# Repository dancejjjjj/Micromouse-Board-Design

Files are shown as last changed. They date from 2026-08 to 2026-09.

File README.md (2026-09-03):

# Micromouse Hardware Design (KiCad)

Hardware schematics and design files for an autonomous Micromouse robot based on the **ESP32-S3 SuperMini**.

---

> ⚠️ **IMPORTANT NOTICE:**  
> The physical hardware of this robot is built entirely on a **Prototype Board (Perfboard/Dot board)** using manual point-to-point soldering.  
> The included **PCB layout file (`.kicad_pcb`) is provided for reference only** (visualizing routing logic and footprint planning) and **has NOT been tested or validated for direct PCB manufacturing**. Please refer to the **Schematic (`.kicad_sch`)** for wiring connections when assembling on a proto-board or designing your custom PCB.

---

## 🧩 Bill of Materials (Key Components)

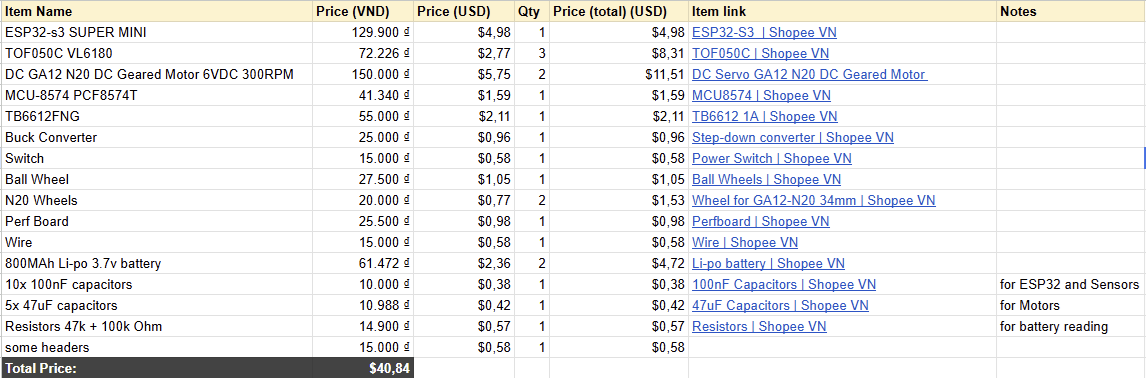
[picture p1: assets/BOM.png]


Google sheet link here:
https://docs.google.com/spreadsheets/d/1piouLKvGbAHOj3b3Lox_jSpBq9OYytLLw8UId9fDQRM/edit?usp=sharing

---

## 📁 Repository Structure

```text
.
├── pcb/
│   ├── micromouse.kicad_pro     # KiCad Project File
│   ├── micromouse.kicad_sch     # Full Circuit Schematic (Primary reference)
│   └── micromouse.kicad_pcb     # Reference PCB Layout (Do NOT fabricate directly)
|   
├── BOM.csv
└── README.md
```
## View it 
https://kicanvas.org/?repo=https%3A%2F%2Fgithub.com%2Fdancejjjjj%2FMicromouse-Board-Design%2Ftree%2Fmain%2Fpcb

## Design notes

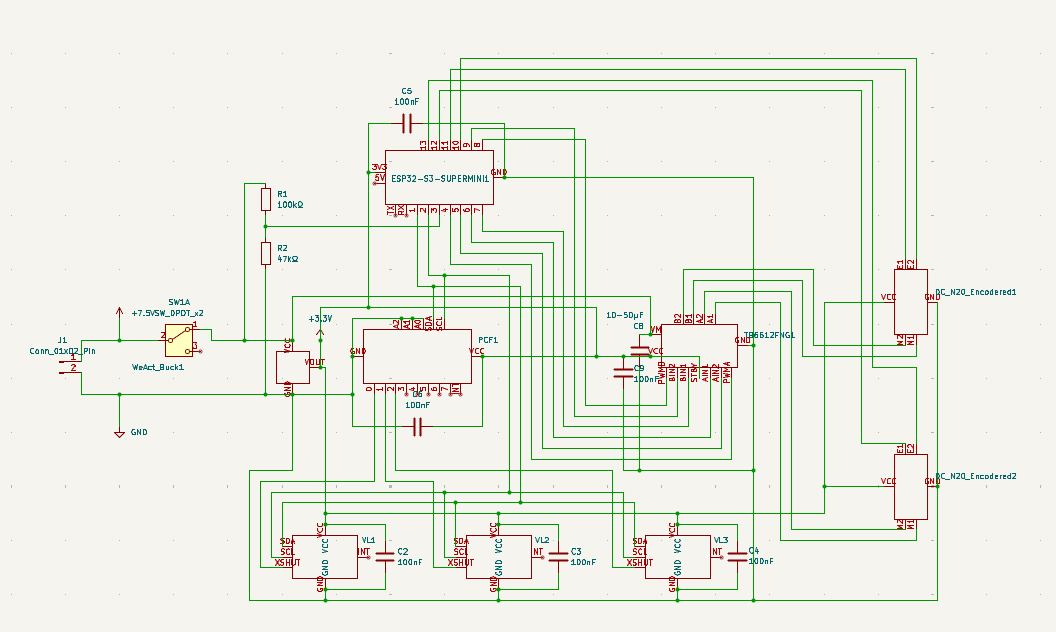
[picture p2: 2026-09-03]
assets/Schematic.png

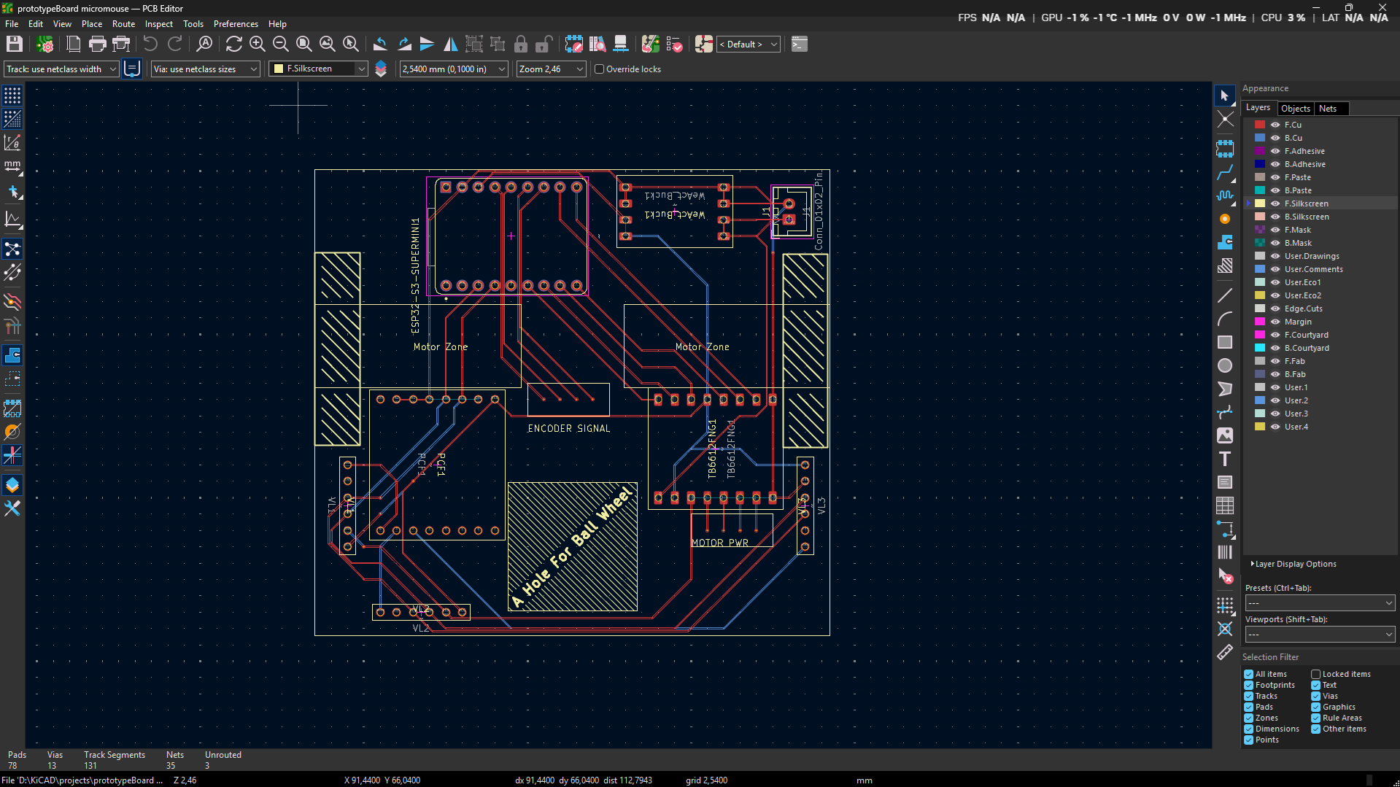
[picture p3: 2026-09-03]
assets/PCB.png

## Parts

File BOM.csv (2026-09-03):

Item Name | Price (VND) | Price (USD) | Qty | Price (total) (USD) | Item link | Notes
ESP32-s3 SUPER MINI | 129.900 ₫ | $4,98 | 1 | $4,98 | https://shopee.vn/ESP32-S3-SuperMini-WiFi-Bluetooth-BLE-5.0-Type-C-Dev-Board-240MHz-4MB-Flash-Ch%C3%ADnh-H%C3%A3ng-i.298106917.46503331606
TOF050C VL6180 | 72.226 ₫ | $2,77 | 3 | $8,31 | https://shopee.vn/M%C3%B4-%C4%91un-c%E1%BA%A3m-bi%E1%BA%BFn-ph%E1%BA%A1m-vi-TOF050C-TOF200C-TOF400C-Kho%E1%BA%A3ng-c%C3%A1ch-chuy%E1%BA%BFn-bay-ToF-%C4%91%E1%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
DC GA12 N20 DC Geared Motor 6VDC 300RPM | 150.000 ₫ | $5,75 | 2 | $11,51 | https://hshop.vn/dong-co-dc-giamtoc-ga12-n20-encoder
MCU-8574 PCF8574T | 41.340 ₫ | $1,59 | 1 | $1,59 | https://shopee.vn/Ah-ROBOT-%E3%80%91-PCF8574-PCF8574T-I-O-cho-giao-di%E1%BB%87n-c%E1%BB%95ng-I2C-IIC-H%E1%BB%97-tr%E1%BB%A3-m%C3%B4-%C4%91un-m%E1%BB%9F-r%E1%B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
TB6612FNG | 55.000 ₫ | $2,11 | 1 | $2,11 | https://shopee.vn/Tr%C3%ACnh-%C4%90i%E1%BB%81u-Khi%E1%BB%83n-%C4%90%E1%BB%99ng-C%C6%A1-K%C3%A9p-TB6612-1A-TB6612FNG-Cho-Arduino-L298N-i.578443443.23647942735
Buck Converter | 25.000 ₫ | $0,96 | 1 | $0,96 | https://shopee.vn/WeAct-M%E1%BA%A1ch-Buck-Step-Down-H%E1%BA%A1-%C3%A1p-DC-DC-0.6A-ch%C3%ADnh-h%C3%A3ng-i.882588972.28041630831
Switch | 15.000 ₫ | $0,58 | 1 | $0,58 | https://shopee.vn/5-C%C3%A1i-C%C3%B4ng-t%E1%BA%AFc-g%E1%BA%A1t-3-ch%E1%BA%A5u-on-off-(lo%E1%BA%A1i-t%E1%BB%91t).-C%C3%B4ng-t%E1%BA%AFc-MTS102-6A-125V-3A-250V.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
Ball Wheel | 27.500 ₫ | $1,05 | 1 | $1,05 | https://shopee.vn/B%C3%A1nh-xe-%C4%91a-h%C6%B0%E1%BB%9Bng-con-l%C4%83n-bi-c%E1%BA%A7u-v%C3%B2ng-bi-c%E1%BA%A7u-CY15A-CY25A-lo%E1%BA%A1i-chu%E1%BA%A9n-i.599614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
N20 Wheels | 20.000 ₫ | $0,77 | 2 | $1,53 | https://shopee.vn/B%C3%A1nh-xe-%C4%91%E1%BB%99ng-c%C6%A1-GA12-N20-34mm-i.494330825.8781429510
Perf Board | 25.500 ₫ | $0,98 | 1 | $0,98 | https://shopee.vn/Bo-M%E1%BA%A1ch-%C4%90%E1%BB%A5c-L%E1%BB%97-S%E1%BA%B5n-Nhi%E1%BB%81u-K%C3%ADch-Th%C6%B0%E1%BB%9Bc-Kho%E1%BA%A3ng-C%C3%A1ch-L%E1%BB%97-2.54m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
Wire | 15.000 ₫ | $0,58 | 1 | $0,58 | https://shopee.vn/-Linh-Ki%E1%BB%87n-%C4%90i%E1%BB%87n-T%E1%BB%AD-2M-D%C3%A2y-%C4%90%E1%BB%93ng-1-L%C3%B5i-0.6mm-C%E1%BA%AFm-Tesboard-N%E1%BB%91i-M%E1%BA%A1ch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
800MAh Li-po 3.7v battery | 61.472 ₫ | $2,36 | 2 | $4,72 | https://shopee.vn/Pin-s%E1%BA%A1c-Lipo-3.7V-Dung-L%C6%B0%E1%BB%A3ng-T%E1%BB%AB-50-10000mAh-c%C3%B3-m%E1%BA%A1ch-b%E1%BA%A3o-v%E1%BB%87-pin-cho-tai-nghe-%C4%91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
10x 100nF capacitors | 10.000 ₫ | $0,38 | 1 | $0,38 | https://shopee.vn/-T%C3%BAi-10-con-T%E1%BB%A5-%C4%91i%E1%BB%87n-g%E1%BB%91m-kh%C3%B4ng-ph%C3%A2n-c%E1%BB%B1c-101-102-103-104-i.101915397.52913659231 | for ESP32 and Sensors
5x 47uF capacitors | 10.988 ₫ | $0,42 | 1 | $0,42 | https://shopee.vn/T%E1%BB%A5-H%C3%B3a-Ph%C3%A2n-C%E1%BB%B1c-16V-47uf-100uf-220uf-330uf-470uf-1000uf-2200uf-3300uf-i.1032535693.23773465937 | for Motors
Resistors 47k + 100k Ohm | 14.900 ₫ | $0,57 | 1 | $0,57 | https://shopee.vn/-Combo-50-%C4%90i%E1%BB%87n-Tr%E1%BB%9F-5-V%C3%B2ng-M%C3%A0u-1-4W-Sai-S%E1%BB%91-1-0.25W-4-V%C3%B2ng-M%C3%A0u-5-Tr%E1%BB%8B-S%E1%BB%91-T%E1%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 | for battery reading
some headers | 15.000 ₫ | $0,58 | 1 | $0,58
Total Price: | $40,84

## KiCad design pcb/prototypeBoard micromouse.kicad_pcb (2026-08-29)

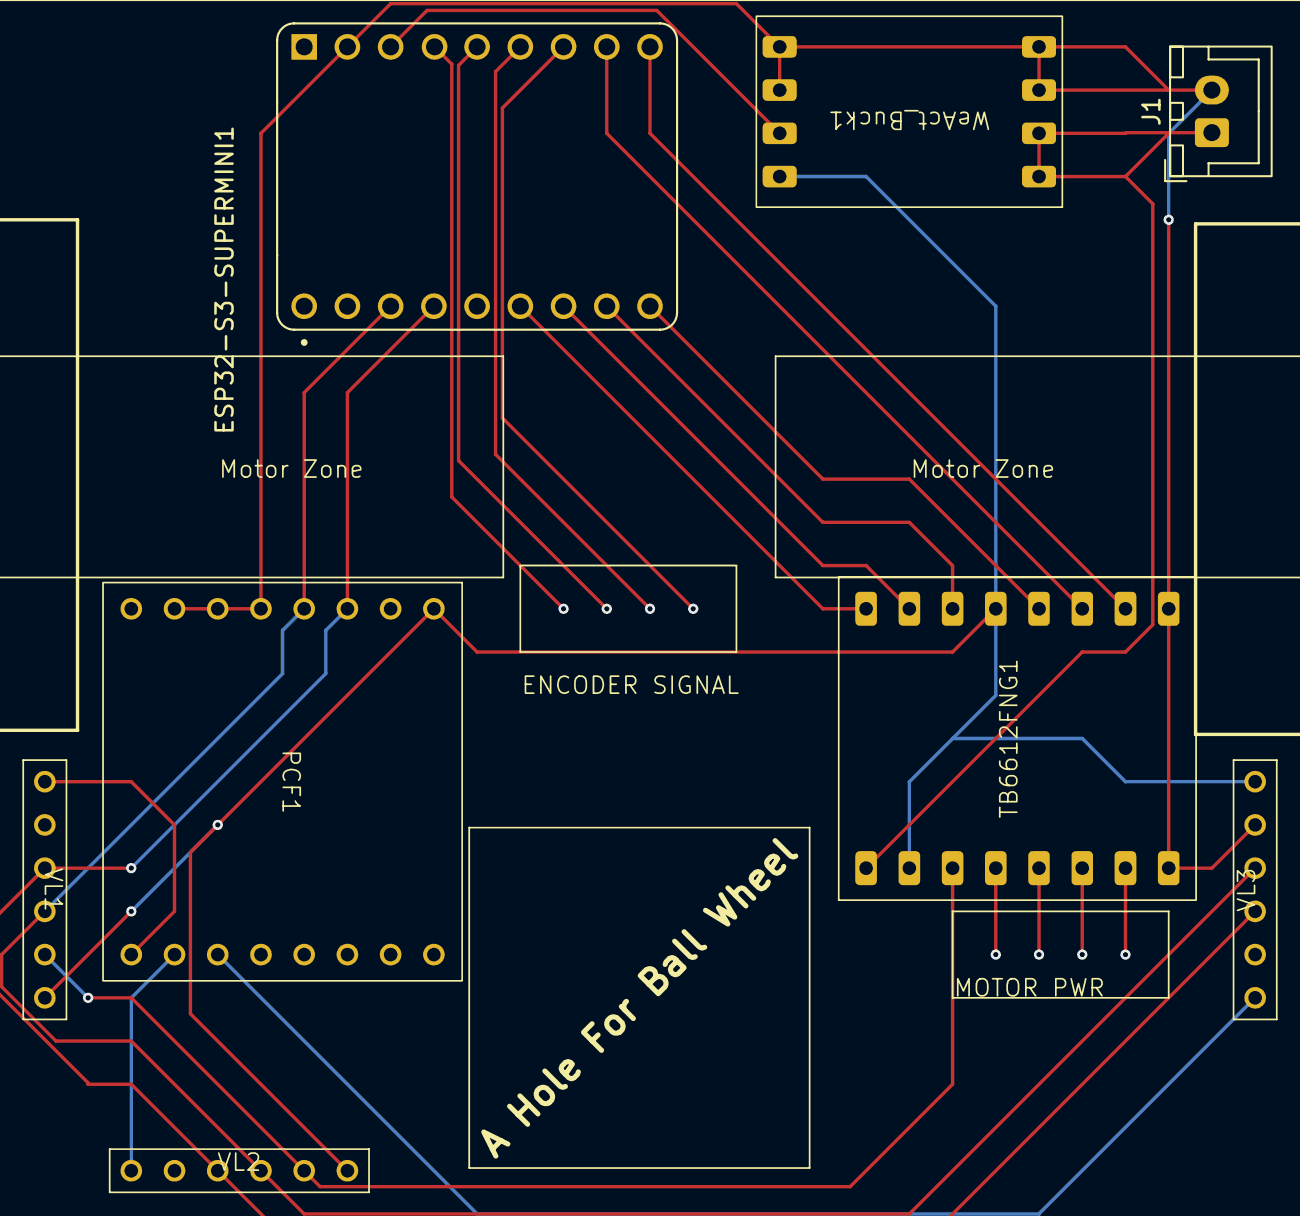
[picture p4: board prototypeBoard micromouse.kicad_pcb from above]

Board: 2 copper layers, 8 parts (0 on the bottom side), 14 nets.

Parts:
ESP32-S3-SUPERMINI1: ESP32-S3-SuperMini
J1: Conn_01x02_Pin; JST_XH_B2B-XH-A_1x02_P2.50mm_Vertical
PCF1: MCU8574-PCF8574T
TB6612FNG1: TB6612FNG
VL1, VL2, VL3: TOF050C_VL6180_PinOnly
WeAct_Buck1: WeAct

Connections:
+3.3V: ESP32-S3-SUPERMINI1.3V3, PCF1.VCC, TB6612FNG1.STBY, TB6612FNG1.VCC, VL1.VCC, VL2.VCC, VL3.VCC, WeAct_Buck1.VOUT
+7.5V: J1.1, TB6612FNG1.VM, WeAct_Buck1.VCC
GND: ESP32-S3-SUPERMINI1.GND, J1.2, PCF1.A0, PCF1.A1, PCF1.A2, PCF1.GND, TB6612FNG1.GND, VL1.GND, VL2.GND, VL3.GND, WeAct_Buck1.GND
unnamed: ESP32-S3-SUPERMINI1.1, PCF1.SDA, VL1.SDA, VL2.SDA, VL3.SDA
unnamed: ESP32-S3-SUPERMINI1.2, PCF1.SCL, VL1.SCL, VL2.SCL, VL3.SCL
unnamed: ESP32-S3-SUPERMINI1.4, TB6612FNG1.PWMA
unnamed: ESP32-S3-SUPERMINI1.5, TB6612FNG1.AIN2
unnamed: ESP32-S3-SUPERMINI1.6, TB6612FNG1.AIN1
unnamed: ESP32-S3-SUPERMINI1.7, TB6612FNG1.BIN1
unnamed: ESP32-S3-SUPERMINI1.8, TB6612FNG1.PWMB
unnamed: ESP32-S3-SUPERMINI1.9, TB6612FNG1.BIN2
unnamed: PCF1.0, VL1.XSHUT
unnamed: PCF1.1, VL2.XSHUT
unnamed: PCF1.2, VL3.XSHUT

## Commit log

2026-08-29 Delete prototypeBoard micromouse.recovered.2026-08-29_162205.kicad_pcb
    old backup file
    [prototypeBoard micromouse.recovered.2026-08-29_162205.kicad_pcb]
2026-08-29 Delete ~prototypeBoard micromouse.kicad_pro.lck
    useless file
2026-08-29 Delete ~prototypeBoard micromouse.kicad_pcb.lck
    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
2026-08-29 Just Move files
    [prototypeBoard micromouse.kicad_pcb, prototypeBoard micromouse.kicad_sch]
2026-08-31 add switch + capacitors
    [prototypeBoard micromouse.kicad_sch]
2026-09-03 Update BOM Image
2026-09-03 Fix BOM file
    [BOM.csv]
2026-09-03 Fix BOM file 2
    [BOM.csv]
2026-09-03 fix BOM file broken link
    [BOM.csv]
2026-09-03 move BOM.csv to root, relocate files, edited kicanvas link
    [BOM.csv]
2026-09-03 relocation fix
    [prototypeBoard micromouse.kicad_pcb, prototypeBoard micromouse.kicad_sch]
